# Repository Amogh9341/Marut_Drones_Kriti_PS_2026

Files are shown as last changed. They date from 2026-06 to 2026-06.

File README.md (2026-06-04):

# Drone-Based Seedball Dispersal Payload
**Aeromodelling Marut Drones | Kriti '26 | IIT Guwahati | Hostel ID: 2651**

---

## Problem Statement

Manual reforestation is precise but slow. Traditional aerial broadcasting is fast but wasteful — seeds cluster, land on unsuitable surfaces, and compete for resources. There is no reliable, autonomous mechanism that drops seedballs one at a time at controlled intervals from a drone, especially when seedball sizes are non-uniform.

---

## Idea

Design a standalone, drone-mounted payload system that:
- Releases seedballs **one at a time** at adjustable intervals (1–5 seconds)
- Handles **non-uniform spherical seedballs** (15–35 mm diameter)
- Operates **autonomously** — detects and resolves jams without human intervention
- Fits within **20 kg** total mass and **300 × 350 × 350 mm** volume

Design approach: *working backwards from failure* — identify what goes wrong in seed dispensing systems first, then build around those failure modes.

---

## Implementation

### Architecture: Three-Stage Modular Pipeline

**Stage 1 — Hopper Assembly**
- Gravity-fed tapered storage container
- Integrated rotational agitator (DC geared motor) prevents bridging and seed stagnation
- Capacity: up to 20 kg total (mechanism + seedballs)

**Stage 2 — Horizontal Screw Conveyor (Auger)**
- Meters seedballs from hopper to dispensing stage
- Acts as a buffer — decouples hopper pressure from dispensing rate
- Driven by a stepper motor; monitored via TMC2209 driver for stall detection
- On jam: auto-reverses motor up to 3 times, then halts safely

**Stage 3 — Disc Dispensing Mechanism**
- Continuously rotating disc with 3 conical radial grooves at varying angles
- Accommodates all seedball sizes (15–35 mm) without manual adjustment
- Releases exactly one seedball per cycle through a single drop point

### Control System
- **Microcontroller:** ESP32
- **Motor driver:** TMC2209 (built-in stall detection — no external sensors needed for jam detection)
- **Interface:** Bluetooth / Wi-Fi input for start/stop and drop interval setting
- **Fault logic:** Jam detected → reverse motor → retry up to 3 times → halt if unresolved

### Materials
- **Carbon fiber** — structural frame (lightweight, high tensile strength)
- **Acrylic sheet** — housing panels (easy to fabricate, optically clear for inspection)

### Key Design Tolerances
- Internal flow paths sized at **1.15× the largest seedball diameter** to allow for size variation without multi-ball release
- Seed drop interval: **1–5 seconds** (adjustable)

---

## Prototype

Built at **1:2 scale** (14 × 17 × 22 cm footprint) using carbon fiber and acrylic.  
Test seedballs: ~13 mm diameter (50% scale).  
Validated: gravity-fed dynamics, auger flow consistency, stall detection, and automated anti-jam routine.

---

## Limitations

- Risk of multi-seedball release cannot be fully eliminated
- Sensitive to mechanical tolerances in screw and disc assemblies
- Moisture and debris can affect flow behaviour
- Maintenance automation (dust/earth accumulation) is unsolved

---

## Future Scope

- GPS-based location-aware seedball deployment
- Active gating for improved single-ball precision
- Multi-drone swarm synchronization for large-scale restoration
- Automated rinsing/cleaning mechanism

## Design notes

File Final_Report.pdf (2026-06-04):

February 2026

Final Technical Report

Kriti ’26

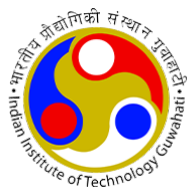
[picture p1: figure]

——————————————————–

AEROMODELLING MARUT DRONES

——————————————————–

Hostel ID:

2651

## Contents

Kriti ’26 | Hostel : 2651

## 1 Introduction

Drone based reforestation addresses one of the biggest challenges in environmental restoration: how to plant on a scale without sacrificing survival rates. Manual planting is precise but slow, while traditional aerial broadcasting where seeds are scattered in bulk is fast but wasteful. Many seeds end up clustered together or fall on unsuitable surfaces such as rocks, reducing their chances of survival. A drone system that releases seedballs one at a time, at controlled intervals, offers a more balanced approach combining efficiency with precise placement for large-scale planting efforts.

By dropping seedballs at regular intervals, each plant gets a equal share of sunlight, water, and nutrients from the soil, reducing unnecessary competition. Without this controlled spacing, seeds often fall in clusters, leading to overcrowded patches where only the strongest seedlings survive. At the same time, other areas are left empty, making them more prone to invasive species taking root.

### 1.1 Importance of timing and control

Consistent timing and accurate drop control are not just operational details they play an important role in ensuring meaningful and sustainable results. In drone based reforestation, the overall success of plantation efforts depends greatly on how precisely seed placement is managed during flight. When release intervals are uniform, plant spacing becomes more predictable, survival rates improve, and land coverage becomes more efficient.

1.1.1 Uniform Timing: It keeps the drone’s speed and seed release perfectly in sync, so the drops form a pattern, regardless of wind or terrain.

1.1.2 Seed Drop Control: Guarantees that only one seedball is released at a time, preventing mechanical jams and ensuring that the seedballs are used efficiently.

### 1.2 Problem Definition

The primary challenge is to address the limitations of traditional manual reforestation—such as high labor costs and limited access to rough or protected terrains—by utilizing drone technology. Current aerial seeding solutions are often hindered by mechanical jamming caused by non-uniform seedball sizes and a lack of precision control over dispensing rates. Consequently, there is a need for a reliable and intelligent payload system that can autonomously manage seedball dispersal in remote environments.

### 1.2.1 Project Scope and Requirements

We are tasked with designing and developing a standalone seedball dropping mechanism to be mounted on a drone. The project focuses exclusively on the payload system; the drone’s flight control and propulsion are out of scope.

### 1.2.2 Core Requirements:

1.2.2.1 Storage & Capacity: The system must be of up to 20 kg including both the mechanism aswell the seedballs within a maximum volume of 300 mm x 350 mm x 350 mm.

1.2.2.2 Material Handling: It must reliably process non-uniform, irregular spherical seedballs with diameters ranging from 15 mm to 35 mm.

1.2.2.3 Precision Dispensing: The mechanism must allow for adjustable drop intervals between 1 and 5 seconds.

1.2.2.4 Autonomous Intelligence: The system must include onboard electronics like ESP32 and sensors to detect and automatically rectify blockages or jams without human intervention.

### 1.3 Constraints

1.3.1 Mass Limits: The total allowable mass, including the dispensing mechanism and seedball payload, is capped at 20 kg.

### 1.3.2 Physical Constraints

Maximum payload volume: Width: 300 mm, Height: 350 mm, Length: 350 mm Seedball size range: Diameter: 15 mm to 35 mm
Shape: Non-uniform / irregular spherical
Weight optimization for aerial deployment

1.3.3 Controlled seedball drop interval: 1-5 seconds.

### 1.3.4 Vessel and Screw Placement

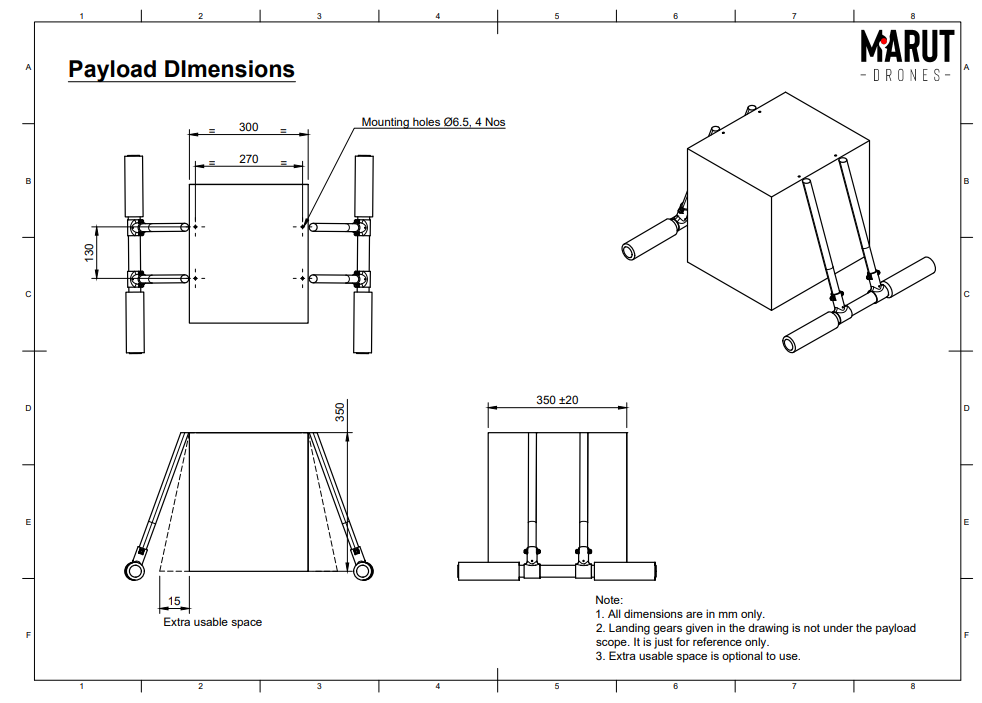
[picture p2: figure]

## 2 Conceptual Ideation

This section covers the evolution of design ideas explored for the seedball dispensing system, highlighting the reasoning behind different concepts and the criteria used to evaluate them.

### 2.1 Objective and Methodology

### 2.1.1 Thinking Structure : Working Backwards

To get a suitable design, we first examined what typically goes wrong in seed dispensing systems rather than assuming an optimal mechanism from the outset while also ensuring that the drop needs to be the same every time, regardless of how full the hopper is.

(a) How do we stop seeds from clumping? Seeds naturally want to stick together; we need to break that bond.
(b) How do we handle different sizes? A mechanism for a 15 mm seed might crush or jam a 35 mm seed.
(c) How do we ensure only one drop? We need a way to “queue” the seeds so they do not all rush out at once.

### 2.1.2 Concept Research Plan

The research was centered on existing industrial systems designed to solve similar problems.

(a) Seed Storage Vessels: The research examined factors that contribute to arch formation such as particle size variation, wall friction, and hopper geometry and explored design strategies to minimize these issues.
(b) Vending Machines: Examined spiral dispensing mechanisms commonly used in vending machines to understand how they isolate and release single items per rotation. The study focused on how rotational pitch, pocket spacing, and controlled motor actuation prevent multiple releases while maintaining consistent and jam-free operation.

### 2.1.3 Purpose of Mechanisms

We simplified the design by dividing the mechanism into basic components, each responsible for one clearly defined function.

(a) Auger: A screw that moves a steady volume of seeds forward.
(b) Disc: A rotating plate that catches one seed and drops it at a set interval.
(c) Agitator: A stirrer that keeps the seeds moving so they don’t get stuck in the hopper.

### 2.2 Design Constraints and Tolerances

The final mechanism was developed within clearly defined mechanical, operational, and environmental constraints to ensure reliable performance under real-world drone deployment conditions.

### 2.2.1 Failsafe Mechanisms

(a) Agitator: Keeps the ”pile” loose so the main screw always has seeds to grab, and prevents arching of seeds.
(b) Directional Reversal: When a stall is identified, the controller initiates a brief reverse rotation of screw for 2% of seed dropping time period to clear the jam and restore normal seed flow.

### 2.2.2 Seed Tolerance Limits

We set a target range for seeds between 15mm and 35mm.

(a) To minimize the risk of jamming, all internal flow paths are designed with some extra space usually around 1.15 times the diameter of the largest seedball. This allows for natural size variation, surface irregularities, and small shifts during motion. As a result, the seedballs move more smoothly through the system, lowering the risk of clogging or mechanical interference..
(b) If the clearance is too small, friction and obstruction can increase to the point where the motor stalls or the mechanism jams. Conversely, if the gap is too large, more than one seedball can slip through at the same time, which affects the accuracy of single drops and disrupts the spacing consistency.

## 3 Mechanism

### 3.1 Engineering Logic & Design Philosophy

The seedball dispersal payload proposed aims to solve the major issues in aerial seeding like flow inconsistency, jamming, and seedball size variation while at the same time, focusing on reliable and autonomous operation within drone’s weight, volume, and power limitations for remote, sensitive environments. It uses gravity assisted feeding combined with controlled mechanical transport to separate bulk storage from dispensing, thus, delivering consistent output across different fill levels and reducing blockages/ uncontrolled release to the minimum.
Using simple, modular, and commercial parts helps to increase manufacturability, maintenance, and scalability, thus, they strike a balance between engineering rigor and practical usability to ensure reliable performance.

### 3.2 Major Hardware Components

The payload consists of three primary mechanical subsystems. The hopper assembly serves as the seedball storage unit and incorporates a tapered geometry with integrated rotational agitation to ensure consistent feeding of non-uniform seedballs. The horizontal screw conveyor (auger) provides controlled, metered transport of seedballs from the hopper to the dispensing stage while acting as a buffer against flow surges. Final release is achieved through disc dispensing mechanism, where a continuously rotating dispensing disk, featuring conical radial grooves with varying incident angles, accommodates different seedball sizes for controlled and sequential discharge through a single release point.

### 3.3 Technical Specifications

The technical specifications of the proposed seedball dispersal payload are defined to ensure reliable operation within the mechanical, electrical, and spatial constraints of a drone-mounted system. Key specifications are summarized below.

(a) Overall mass:
- Maximum total payload mass (mechanism + seedballs): 20 kg.
- Designed with conservative margins to account for dynamic loads and vibration during flight.
(b) Dimensional constraints:
- Maximum length: 350 mm
- Maximum width: 300 mm
- Maximum height: 350 mm
(c) Seedball Parameters:
- Average seedball diameter: 32 mm (varying form 15mm to 35mm)
- Average seedball mass: 27 g
(d) Hopper Assembly:
- Gravity-fed hopper with tapered geometry
- Internal rotational agitator to prevent bridging and stagnation driven using DC geared motor
(e) Screw Conveyor:
- Horizontally mounted threaded screw for metered transport
- Driven by a stepper motor selected based on torque requirements
(f) Dispensing Mechanism:
- Disc with three conical grooves of different angular widths to accommodate seedballs of all varied sizes.
- The open grove collects the balls dropped by the screw and carries it till the dropping hole through its rotation
(g) Control System:
- Microcontroller-based architecture with ESP32

- Controls motor actuation, sensor inputs, and fault response logic
(h) Sensors and Monitoring:
- TMC2209 Motor stall sensing for screw and disc jamming detection
(i) Power and Electrical Interface:
- Powered directly from the drone’s onboard battery
- Includes voltage regulation, protection circuitry, and internal power distribution
(j) Structural Materials:
- Carbon Fiber : Lightweight with High Tensile strength
- Acrylic Sheet : Easy for fabrication and gives optical clarity

### 3.3.1 Intended Payload

The proposed seedball dispersal payload is designed to operate within the constraints of a drone-mounted system while ensuring reliable mechanical and control performance. The total payload mass, including the mechanism and seedballs, is limited to 20 kg, and the system is packaged within approximate dimensions of 350 mm × 300 mm × 350 mm. It is designed to handle seedballs with diameters ranging from 15mm to 35mm, while accommodating reasonable geometric variation. The hopper features a gravity-fed tapered geometry with integrated rotational agitation to prevent stagnation. Seedball transport is achieved using a horizontal screw conveyor, and controlled dispensing is provided by a disc mechanism with varied groves for multiple seedball dimensions. A microcontroller-based system manages actuation, sensing, and fault detection, with power drawn directly from the drone’s onboard supply.

### 3.3.2 Detailed CAD Views of Components

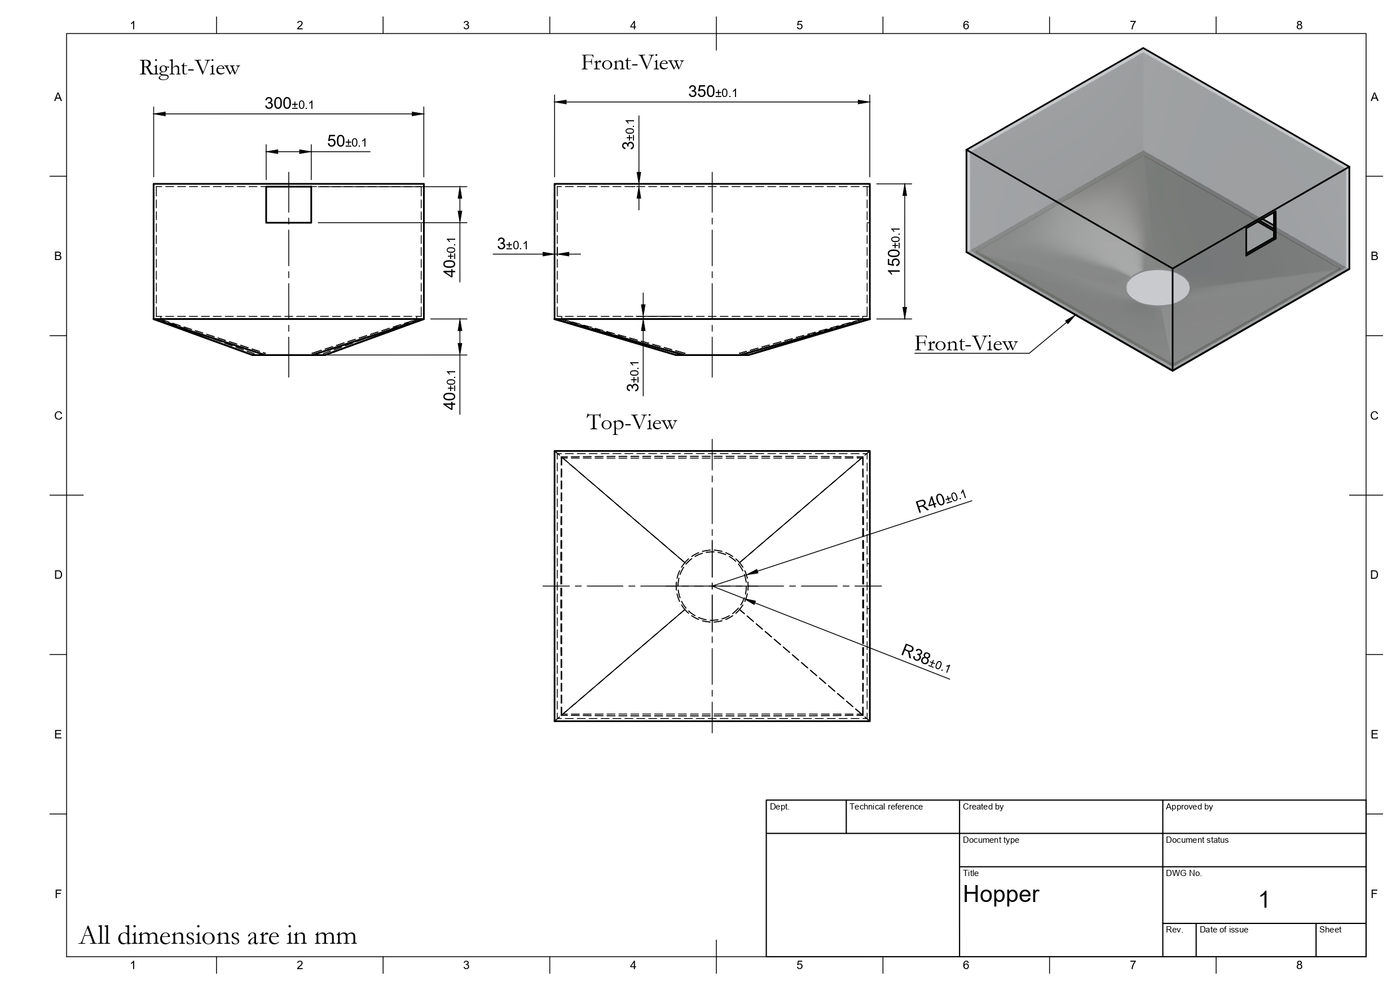
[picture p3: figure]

Figure 1: Hopper

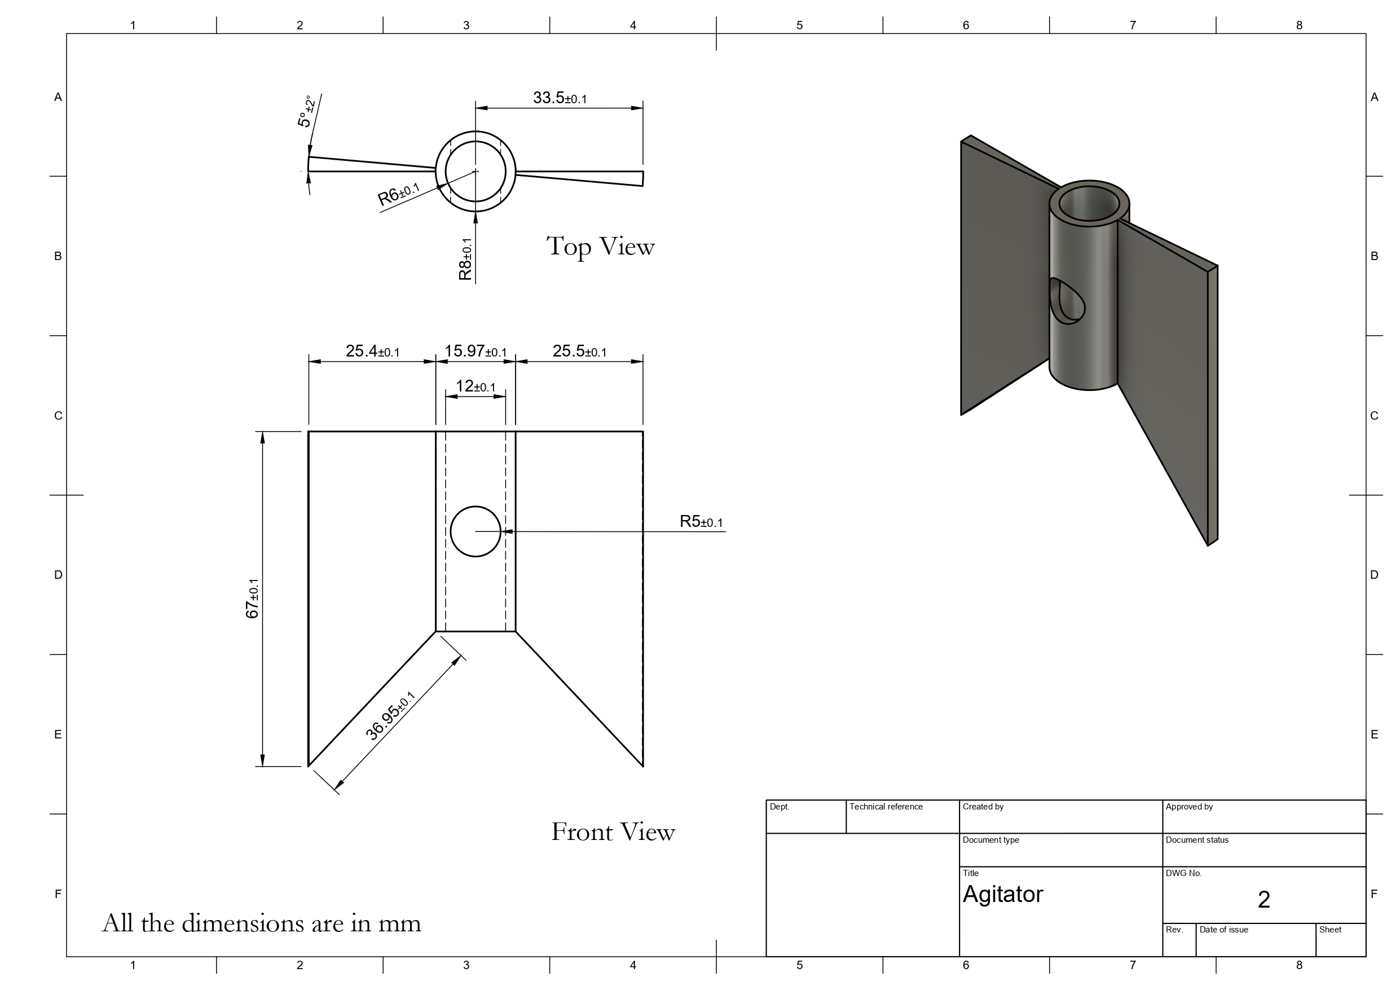
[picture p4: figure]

Figure 2: Agitator

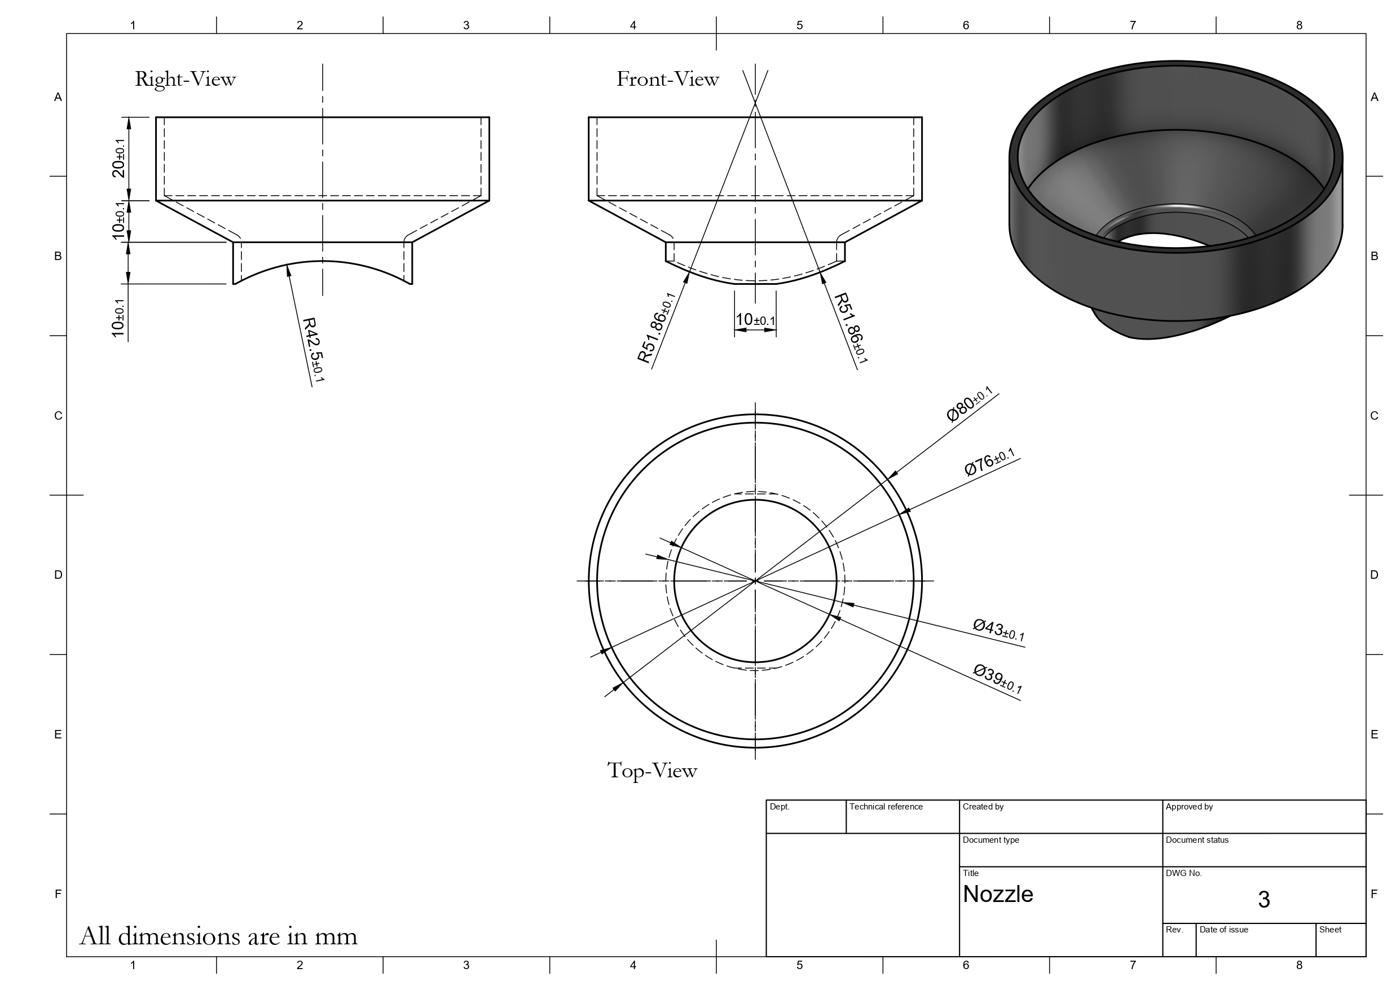
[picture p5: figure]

Figure 3: Hopper Nozzle

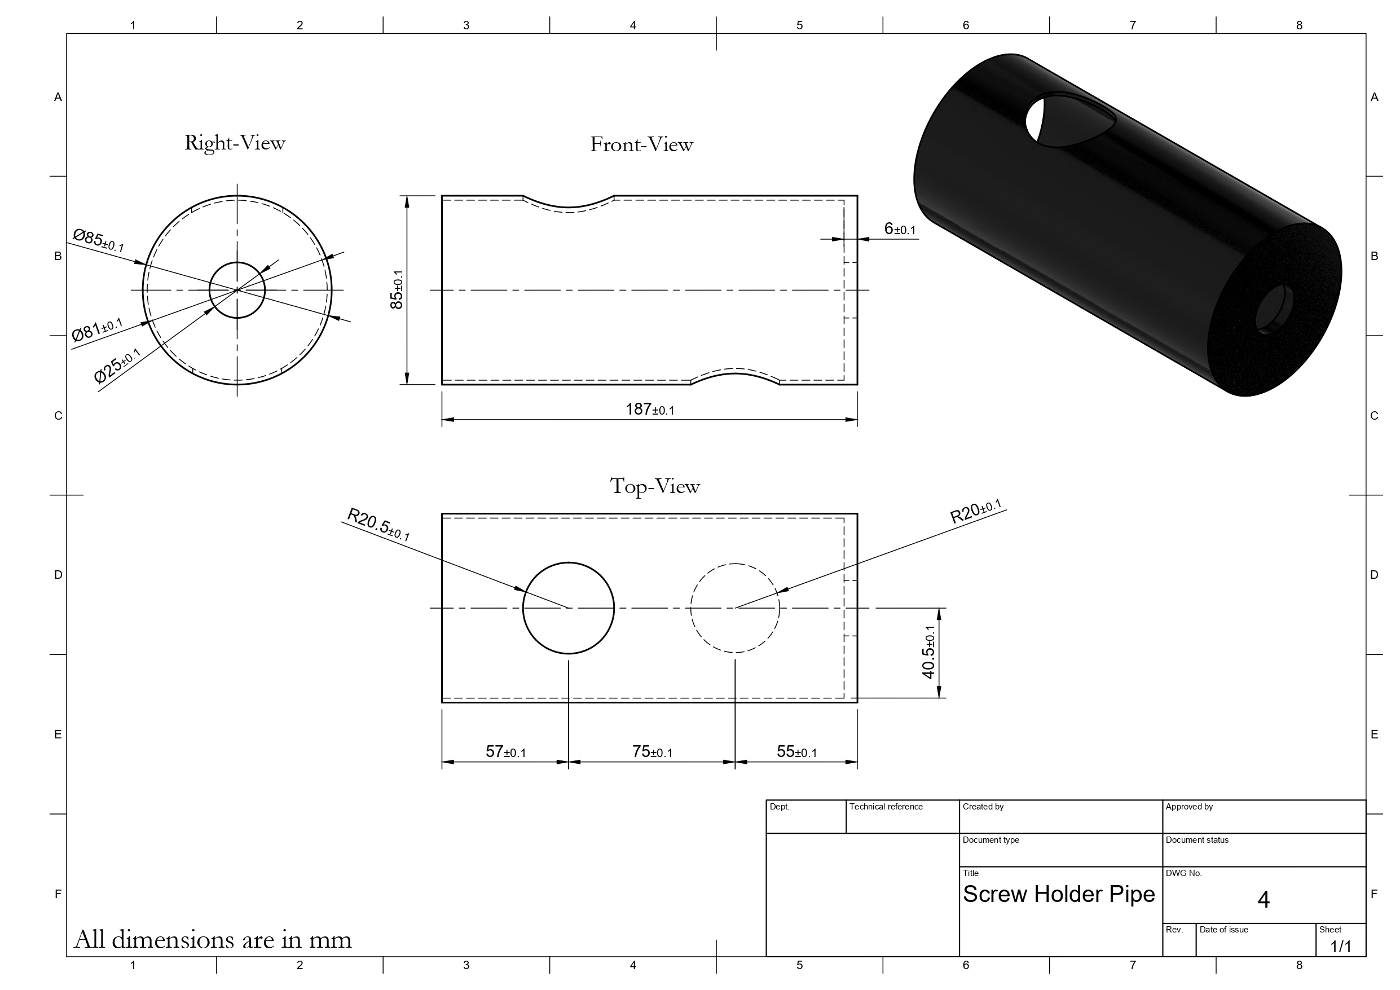
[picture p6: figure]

Figure 4: Screw Holder

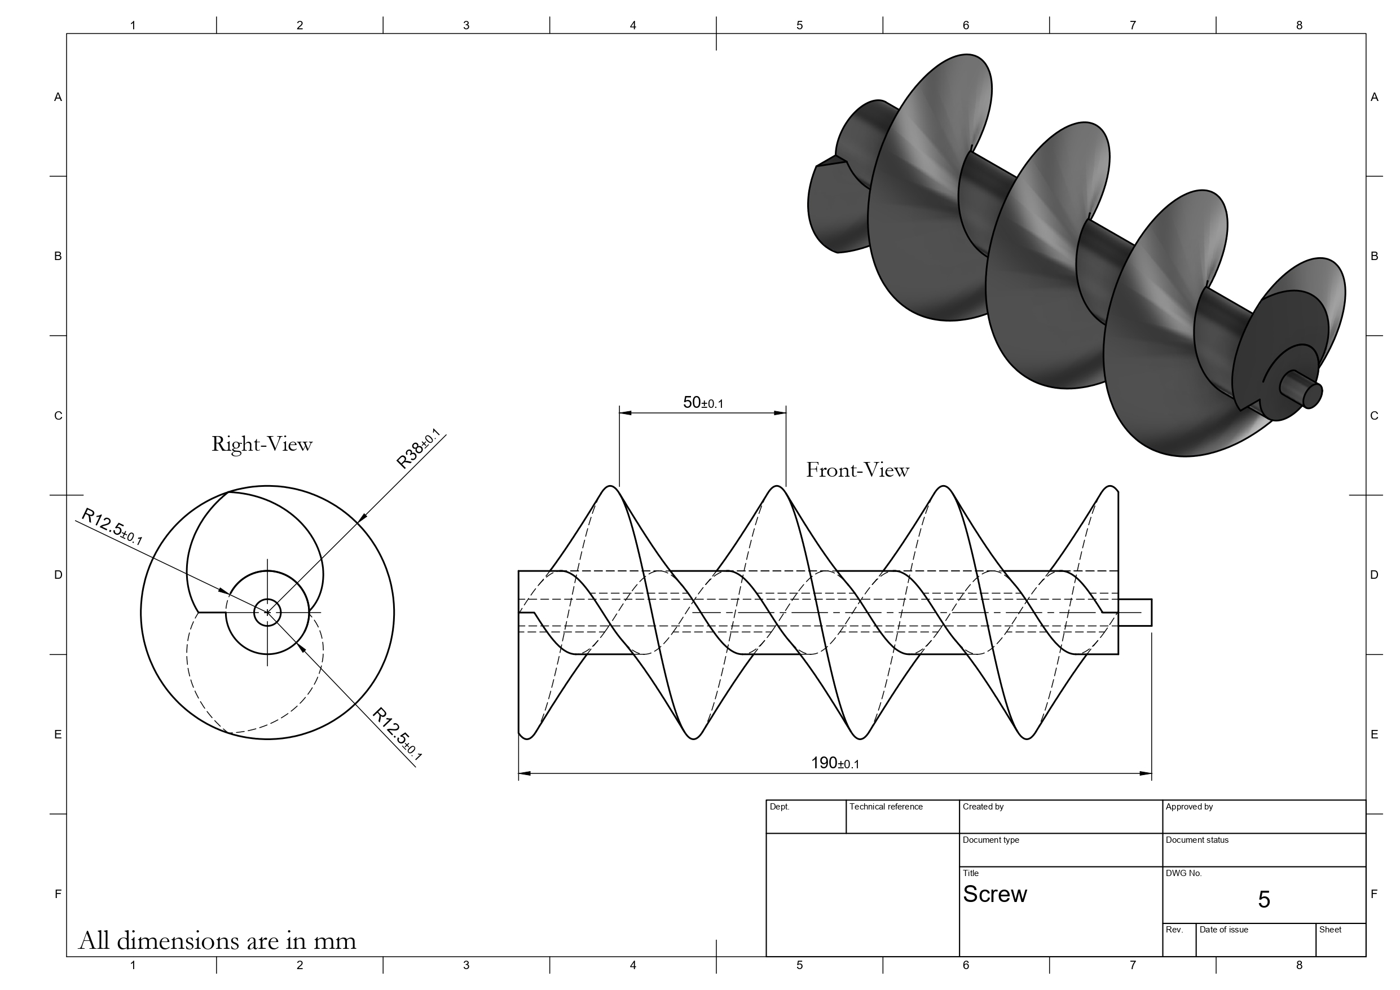
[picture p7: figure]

Figure 5: Screw

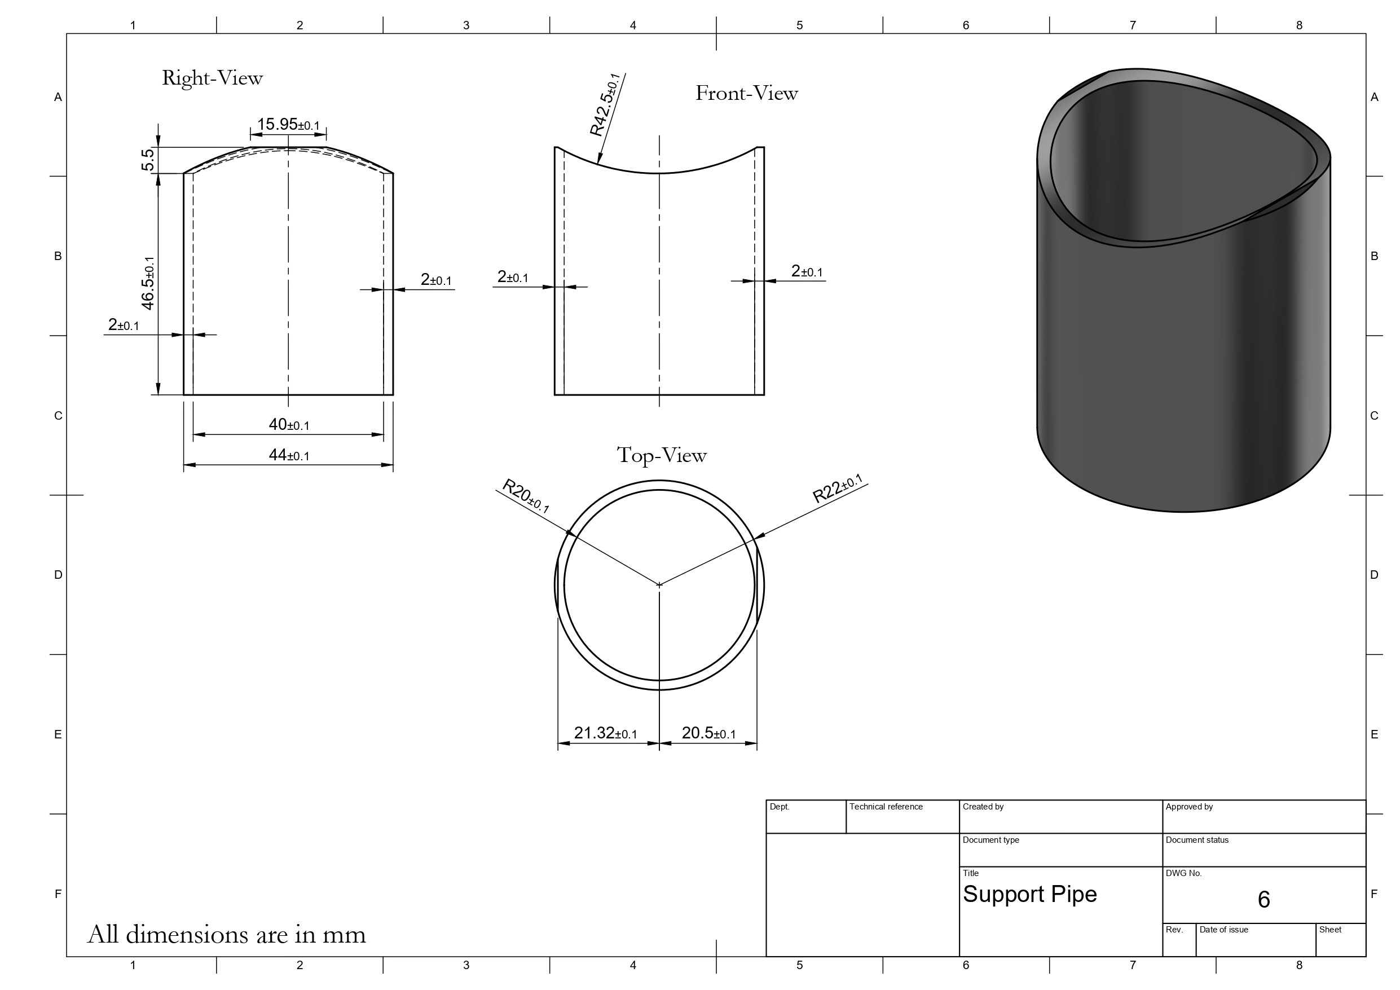
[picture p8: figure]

Figure 6: Support Pipe

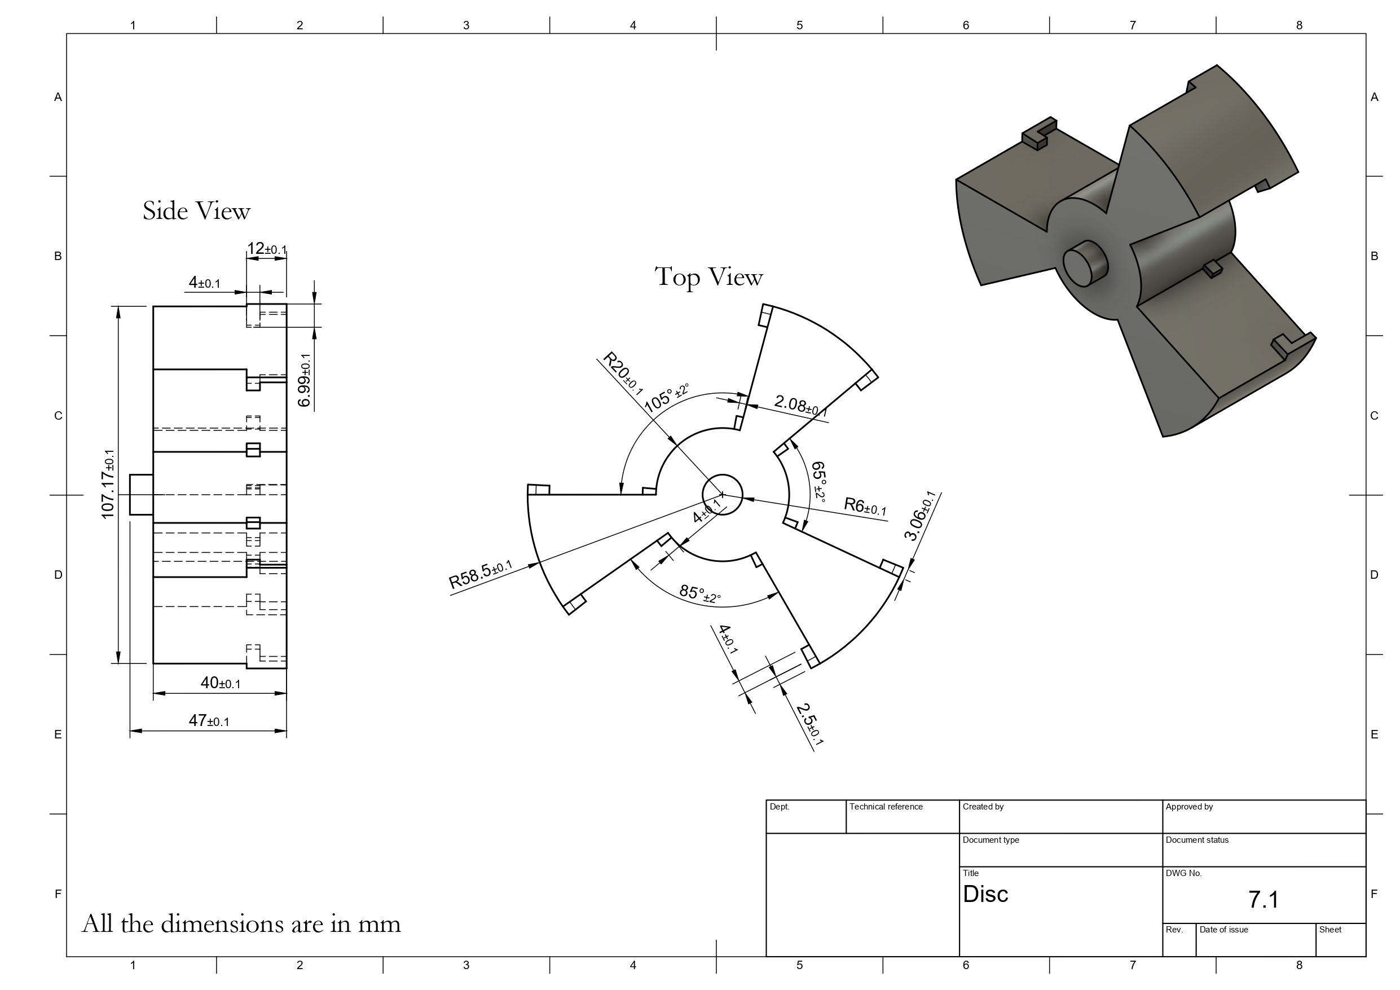
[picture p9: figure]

Figure 7: Disc(A)

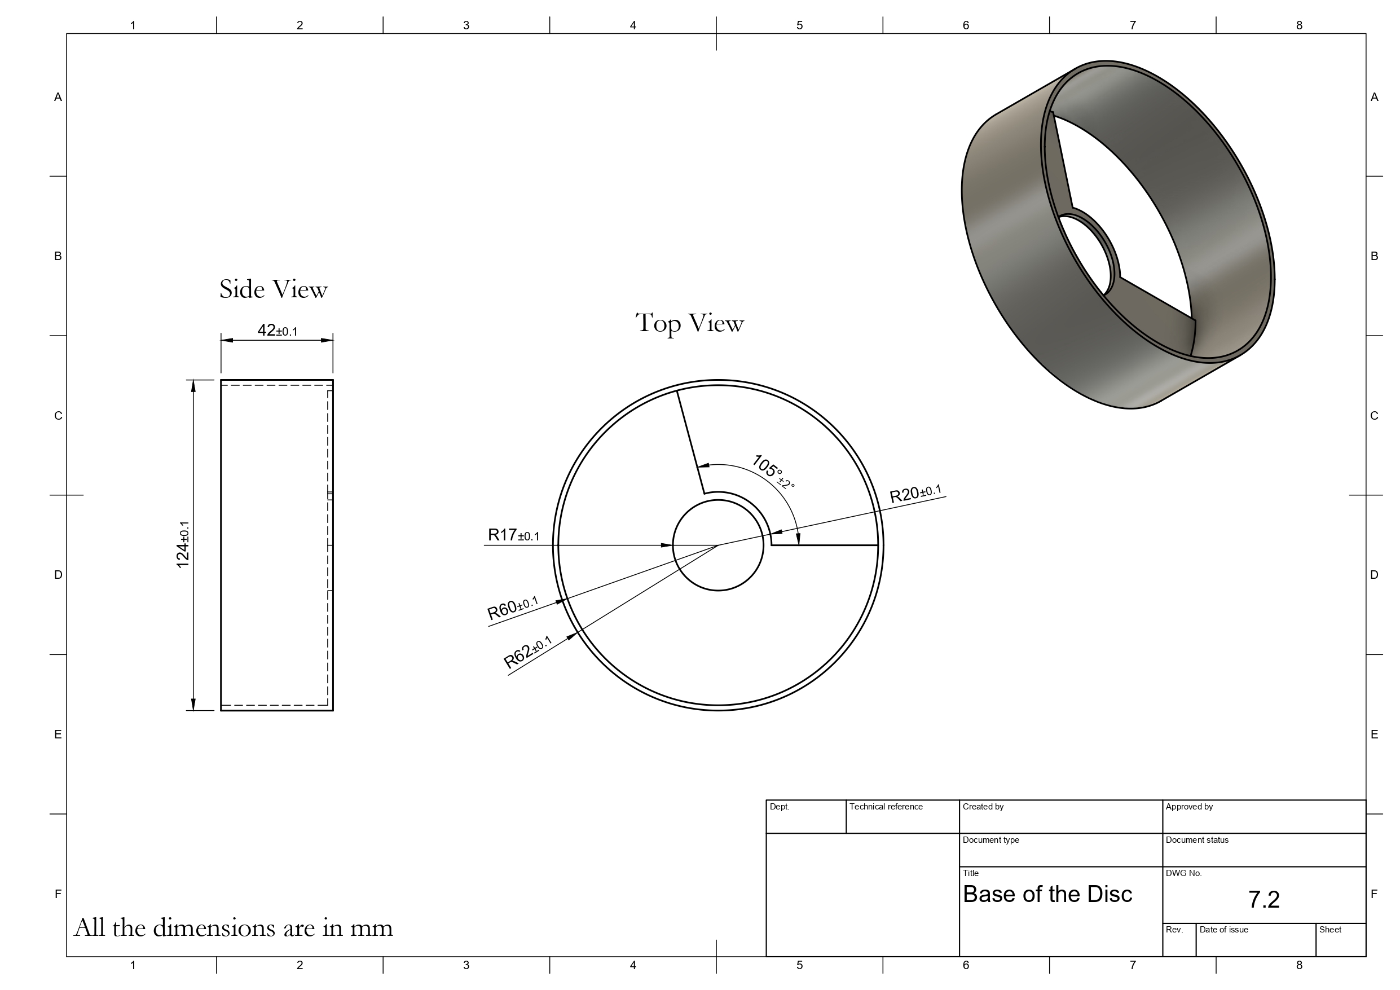
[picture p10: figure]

Figure 8: Disc(B)

### 3.3.3 Cost Analysis

A detailed breakdown of the material and component expenses for the fabricated prototype is provided below.

Table 1: Cost Analysis

Item | Cost (Rs)
Carbon fiber filament | 575
Acrylic Sheet | 360
Microcontrollers
Actuators (3)
Motor Drivers
Miscellaneous costs

Total

### 3.4 Free Body Diagrams

The free body diagrams of the seed-ball in hopper[Fig 9a] and horizontal auger[Fig 9b] are as follows :

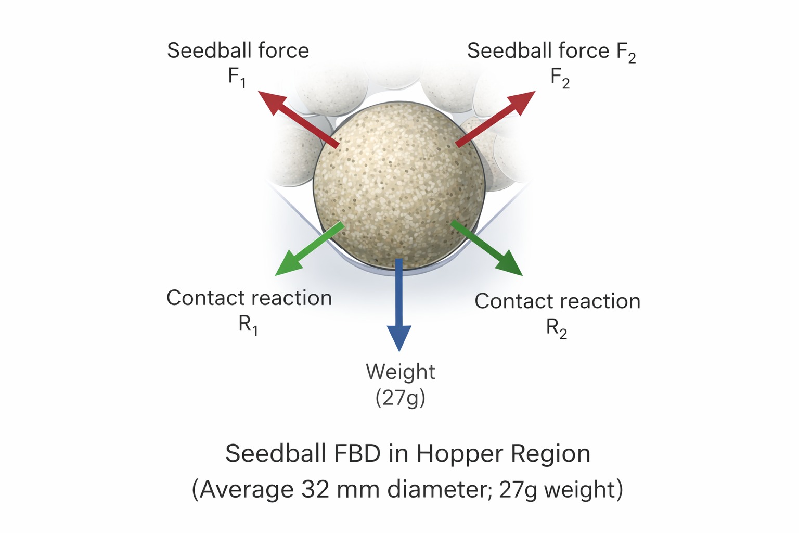
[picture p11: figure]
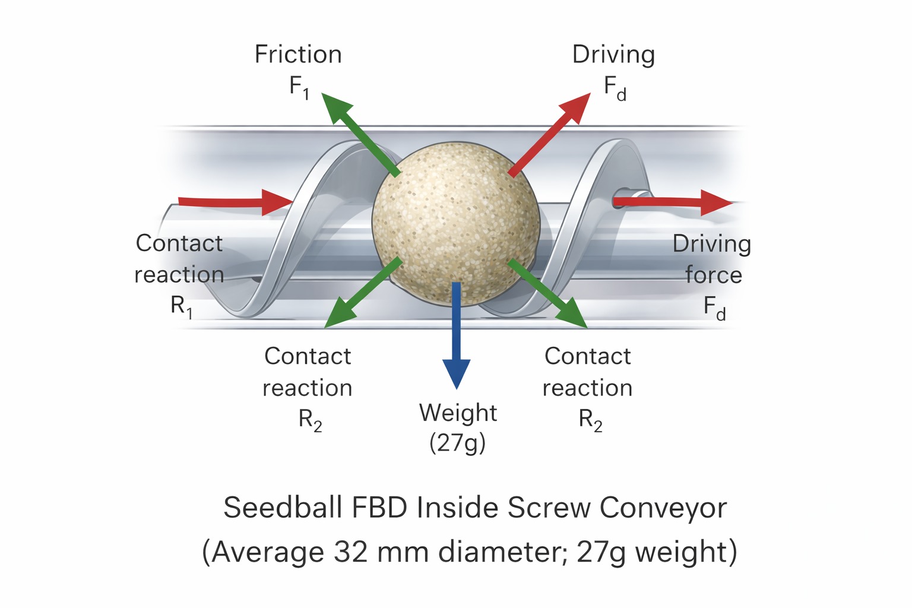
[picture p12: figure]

(a) In Hopper | (b) In Auger

Figure 9: Free Body Diagrams

### 3.5 Control Logic

During operation, seedballs flow from the hopper aided by continuous mechanical agitation to prevent stagnation. They are then metered by a horizontal screw conveyor actively monitored by a TMC2209 stepper driver. If jamming occurs, integrated stall detection triggers an automated anti-jam routine, reversing the motor up to three times to clear the blockage before safely halting the system. Upon exiting the screw, seedballs are sequentially caught by a continuously rotating dispensing disk featuring conical radial grooves with varying incident angles. This geometry dynamically accommodates dimensional variations, ensuring a controlled and repeatable release through a single drop point

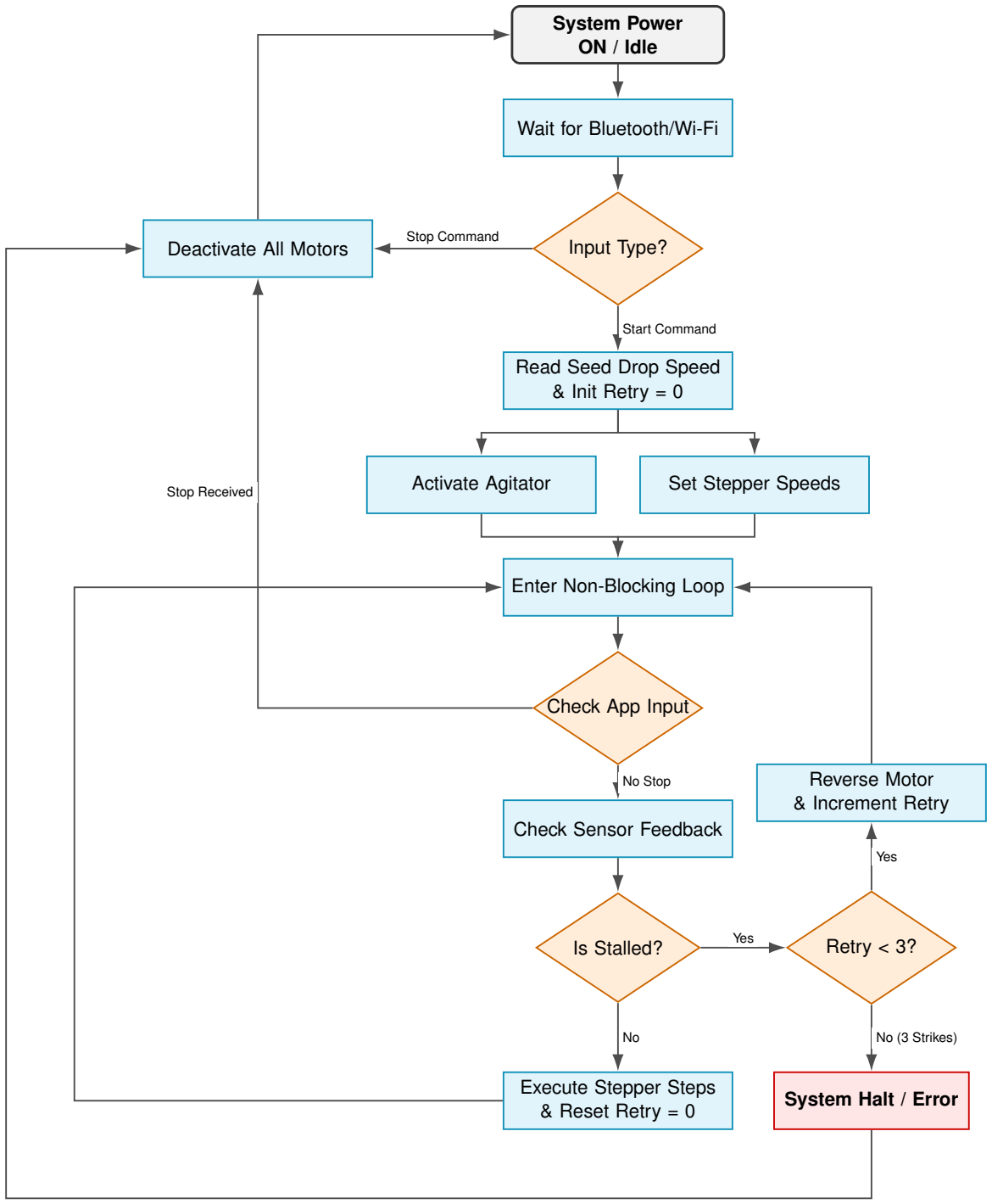
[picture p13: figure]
System Power ON / Idle; Wait for Bluetooth/Wi-Fi; Input Type?; Read Seed Drop Speed & Init Retry = 0; Activate Agitator; Set Stepper Speeds; Enter Non-Blocking Loop; Check App Input; Check Sensor Feedback; Is Stalled?; Execute Stepper Steps & Reset Retry = 0; Deactivate All Motors; Retry < 3?; Reverse Motor & Increment Retry; System Halt / Error; Stop Command; Start Command; No Stop; Yes; No (3 Strikes); Stop Received

Figure 10: Control Flow Logic of the Seedball Mechanism.

### 3.6 Reliability: Blockage Points & Resolution Logic

### 3.6.1 Jamming and Failures

The potential blockage (jamming) points are as follows:

(a) Hopper throat: Arching/bridging, ratholing, interlocking, overloading, moisture clumping, wall adhesion, dead zones.
(b) Agitator: Peripheral dead zones, jamming.
(c) Hopper Outlet: Wedging at lip/screw, misalignment, screw backpressure.
(d) Screw Conveyor: Jams in flights, crushing/lodging, no advance, fill/speed issues, foreign particles, discharge buildup.
(e) Vertical Pipe: Direction changes, bouncing, undersized diameter, stacking, electrostatic adhesion.
(f) Disc Assembly: Seedball wedging in angular grooves, screw-to-disk timing mismatches, debris accumulation, and housing friction.
(g) Drone/Operational: Acceleration/deceleration, tilted flights, vibrations, motor starts/stops, resonance, expansion.
(h) General: Defective seedballs, dust, compaction, partial jams.

### 3.6.2 Detection

The system uses the TMC2209 driver’s built-in stall detection feature. It monitors the load variations for motor and can sense when resistance suddenly increases an indication that a jam may be forming allowing the system to respond quickly and prevent further blockage.

### 3.6.3 Solutions

To mitigate blockages, the system employs a combined hardware-software strategy. Mechanically, continuous hopper agitation prevents initial material bridging, while the dispensing disk’s varied radial grooves safely accommodate different seedball sizes without lodging. If a jam occurs in the screw conveyor, the TMC2209 driver detects the resistance spike via its integrated stall sensing. The control logic immediately triggers an automated anti-jam routine, reversing the motor to clear the obstruction. The system will attempt this up to three times; if successful, normal operation resumes and the retry counter resets. If the jam persists after three consecutive attempts, the system safely halts to prevent hardware damage.

### 3.7 Future Scope

Future developments will focus on enhancing dispensing precision by further minimizing the likelihood of multiseedball release through improved metering strategies and more precise control mechanisms. Additionally, the integration of GPS-based dispersal logic is envisioned to enable location-specific, mission-aware deployment of seedballs. Expanding beyond single-unit operations, future control software could enable multi-drone swarm synchronization for rapid, large-scale ecological restoration.

An issue which has not yet been solved is the automation of maintenance. The accumulation of earth is inevitable and handling it will require some kind of rinsing mechanism which is difficult.

### 3.8 Mechanism Summary

This section summarizes the overall performance, strengths, and limitations of the mechanism, providing a concise evaluation of its feasibility and practical implementation.

### 3.8.1 Overall feasibility statement

The proposed seedball dispersal mechanism is feasible within the mass, dimensional, and power constraints of a drone mounted payload. Its hybrid use of gravity assisted flow and mechanically metered transport enables reliable handling of non-uniform seedballs. With appropriate testing and calibration, the system is well-suited for autonomous aerial deployment.

### 3.8.2 Key Strengths

The major advantages of the mechanism are its ability to tolerate variations in seedball size, its multi stage jam prevention by means of agitation along with stall detection for motor reversal, and a modular design which makes it easier to maintain and upgrade in the future. In addition, sensor based monitoring helps to enhance the overall reliability of the machine during autonomous operation.

### 3.8.3 Risks and Limitations

The main limitations are that it is impossible to completely get rid of the risk of multi seedball release and the system is sensitive to mechanical tolerances in the screw and disc assemblies. Environmental factors like moisture and debris can also impact flow behaviour, which therefore requires controlled testing and refinement of the system.

## 4 Prototype Validation

### 4.1 Prototype Specifications and Scaling

To validate the mechanical logic and flow consistency of the proposed seedball dispersal payload, a physical prototype was fabricated at a 1:2 scale relative to the full-size design.

1. Dimensional Scaling: The original payload was designed to operate within maximum spatial constraints of 350 mm × 300 mm × 350 mm to fit standard drone-mounted parameters. The validation prototype successfully condensed this architecture into a compact 14 cm × 17 cm × 22 cm footprint, effectively halving the volumetric requirements while maintaining the spatial relationships between the hopper, horizontal auger, and dual-disc dispensing stages.
2. Seedball Parameters: To accurately test the gravity-fed dynamics and prevent false-positive jam testing, the prototype utilizes representative seedballs scaled down by approximately 50%. While the full-scale payload is designed to handle seedballs averaging 32 mm in diameter (varying from 15 mm to 35 mm), the validation testing relies on approximately 13 mm diameter test spheres. This ensures the geometric interaction between the seedballs, the rotational agitator, and the screw conveyor flights remains physically accurate to the original design philosophy.
3. Material and Component Selection: Transitioning from the theoretical design to a physical build required adapting the structural materials for rapid manufacturability and testing. The prototype’s primary structural framework and housing utilize a combination of carbon fiber and acrylic sheets, balancing rigidity with weight reduction. The system integrates the core control electronics, including the microcontroller and motor actuation hardware, directly into this scaled-down envelope. This allows for real-world testing of the TMC2209 driver’s stall detection capabilities and the system’s automated fault response logic within a representative physical space

### 4.2 Performance Analytics and Operational Metrics

## 5 Conclusion

The Horizontal Auger with Disc mechanism continues to be a real and mechanically strong solution for the controlled release of seedball drones in the air. This model solves the main issue of aerial reforestation, which is the regulated and even release of non uniform seedballs under the limiting conditions of weight, power, and reliability that come from deployment by a drone while at the same time minimizing the risk of jamming.

1. Decoupled Material Flow
The use of a horizontal screw conveyor as an intermediate buffer decouples the dispensing mechanism from the variable head pressure of the hopper. This isolation ensures predictable and metered material flow, reducing the likelihood of uncontrolled discharge and pressure-induced jamming.
2. Adaptive Precision
The Disc mechanism, incorporating conical openings of different angles made to accomodate different seedball dimensions, enables adaptive handling of seedballs with diameters ranging from 15 mm to 35 mm. This significantly reduces jamming risks commonly encountered in rigid, single-aperture systems and improves operational robustness.
3. Simplified Diagnostic Feedback
Jamming detection is achieved through monitoring motor stalling within the screw conveyor and disc assemblies. TMC2209 driver has stall detection to reliably detect stalling . Upon detection, the control logic can autonomously initiate temporary motor reversal without requiring external sensors.
4. Mass and Energy Efficiency
Combined with a lightweight carbon-fiber structural frame and direct power supply from the drone’s onboard battery, the module remains within the 20 kg payload constraint.
5. Future Scope
While the current configuration provides a robust foundation for reliable seedball dispersal, future iterations will focus on enhancing singulation precision through active gating mechanisms, fail safe operations integrating and mission-aware GPS-based deployment logic.

## 6 References

[1] K. To, P.-Y. Lai, and H. K. Pak, Jamming of Granular Flow in a Two-Dimensional Hopper, Phys. Rev. Lett. 86, 71–74 (2001).

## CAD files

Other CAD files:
CAD/Agitator.f3d
CAD/Assembly.f3z
CAD/Disc.f3d
CAD/Screw.f3z
CAD/Screw_Holder_Pipe.f3z
CAD/Support_Pipe.f3d
CAD/Vessel.f3d
CAD/Vessel_Nozzle.f3z

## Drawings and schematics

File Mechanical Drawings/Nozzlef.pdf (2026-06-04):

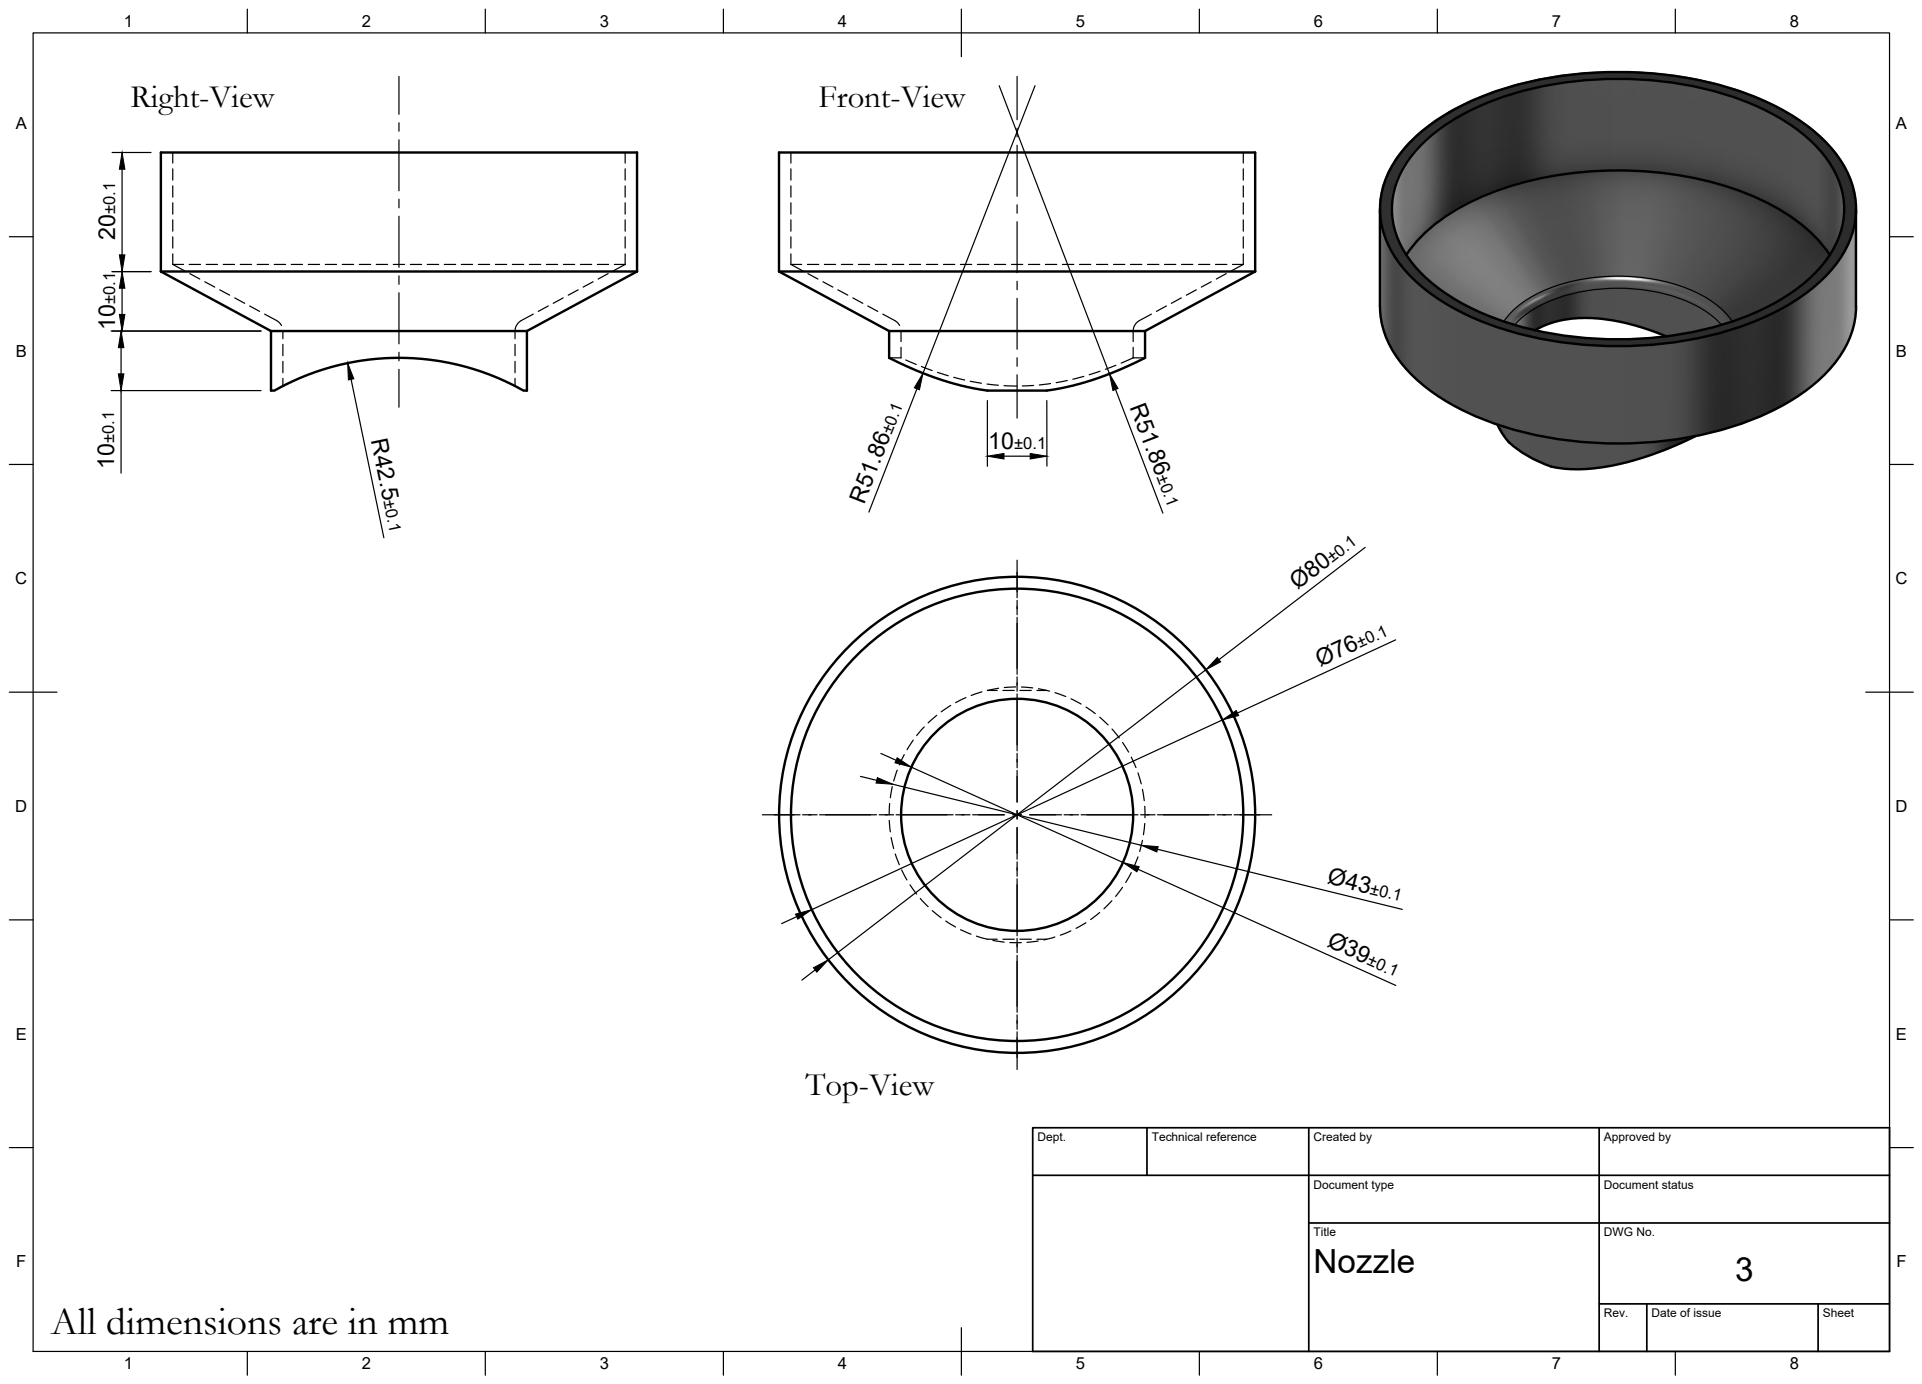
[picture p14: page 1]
Title; DWG No.; Rev.; Date of issue; Sheet; Nozzle

Dept. | Technical reference | Created by | Approved by

Document type | Document status

All dimensions are in mm

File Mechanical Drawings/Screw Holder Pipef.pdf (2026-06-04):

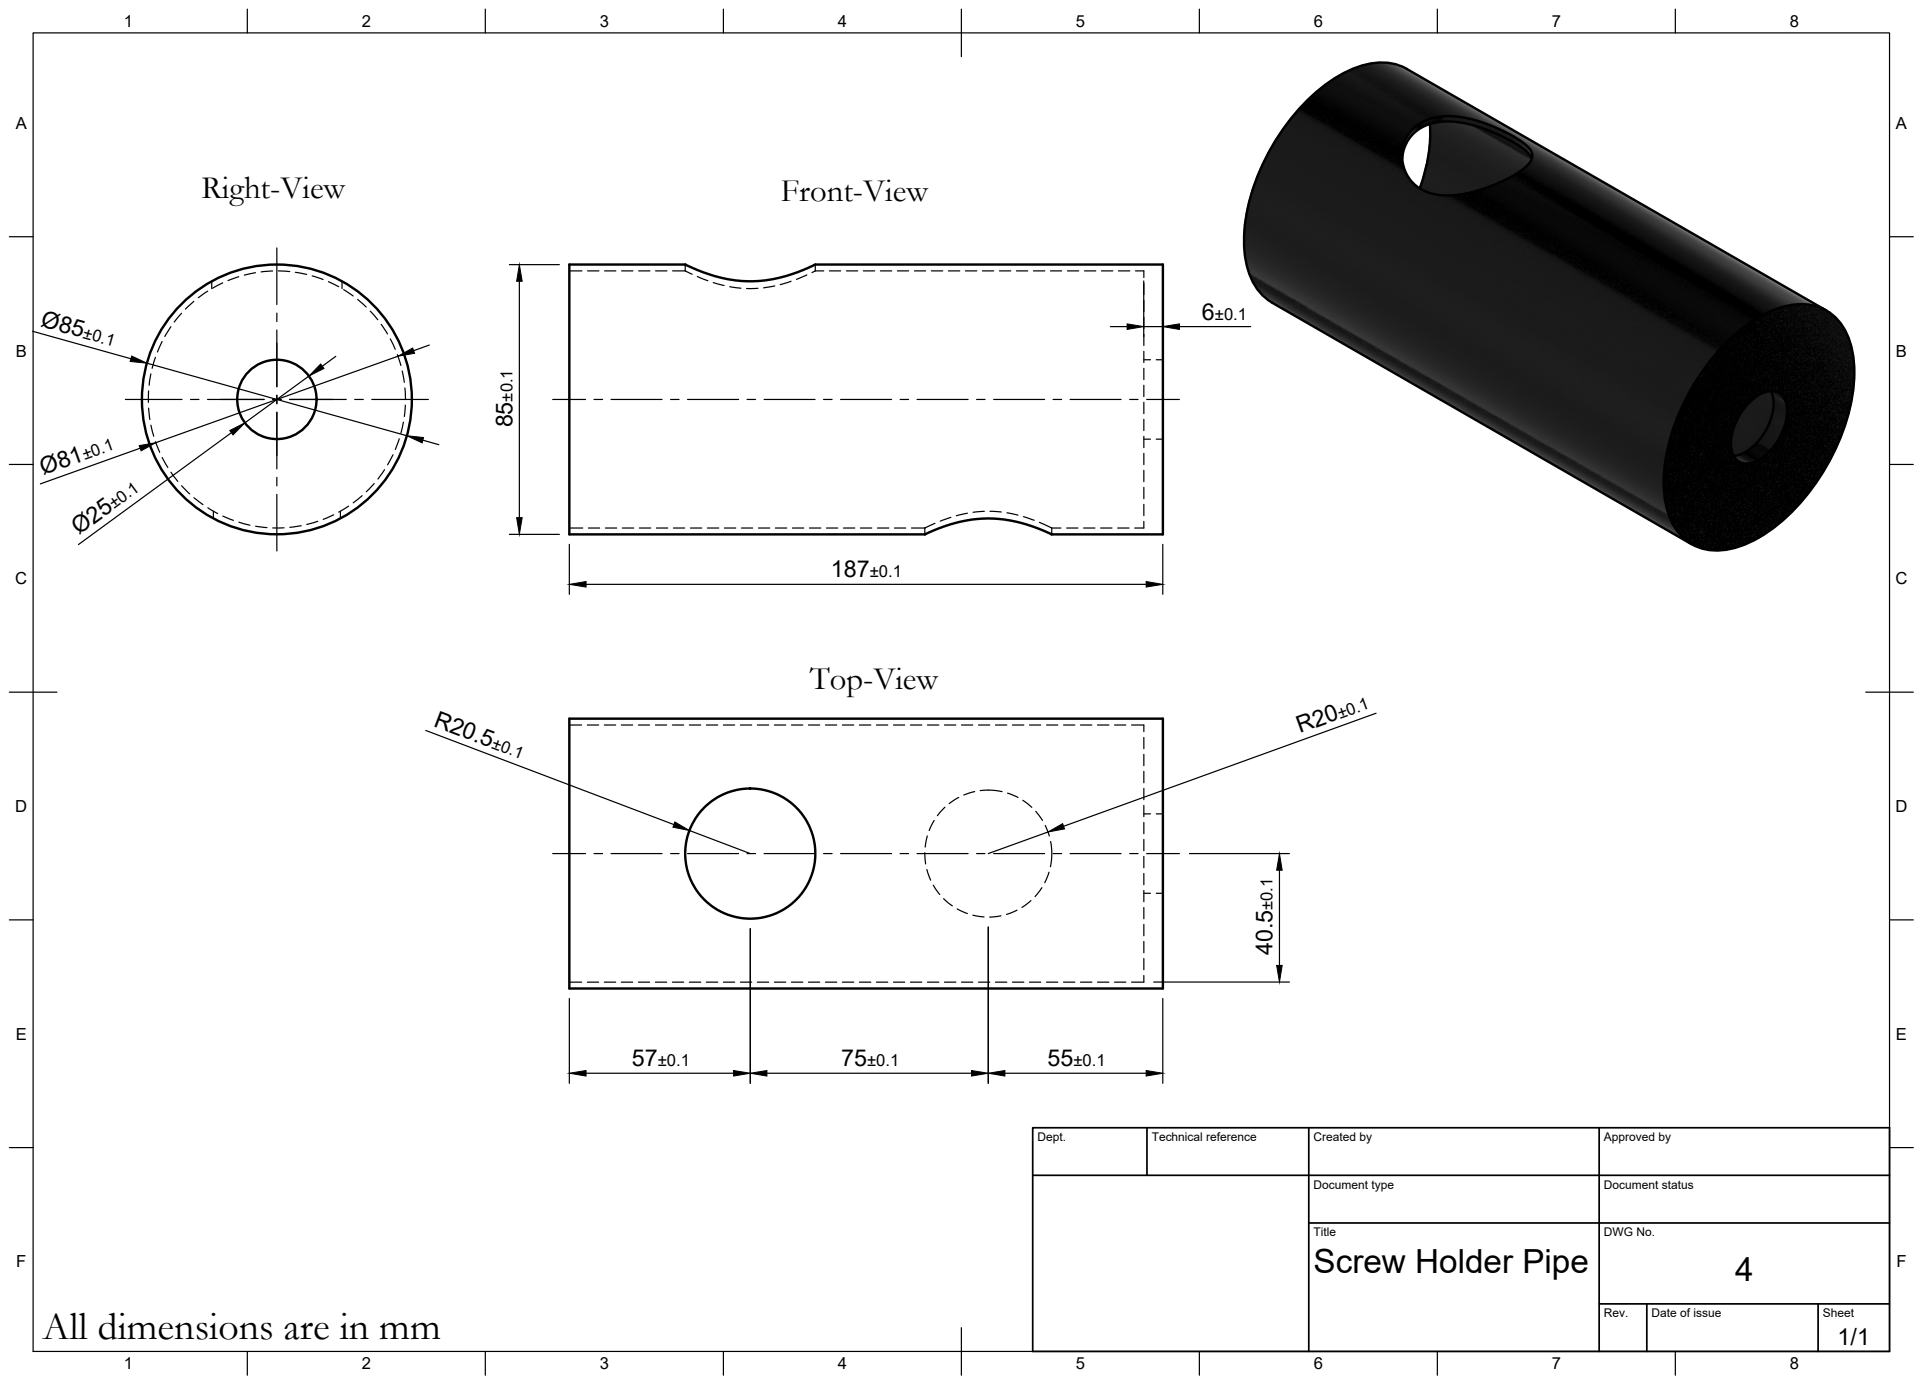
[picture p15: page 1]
Title; DWG No.; Rev.; Date of issue; Sheet; Screw Holder Pipe; Top-View 85±0.1

Dept. | Technical reference | Created by | Approved by

Document type | Document status

All dimensions are in mm

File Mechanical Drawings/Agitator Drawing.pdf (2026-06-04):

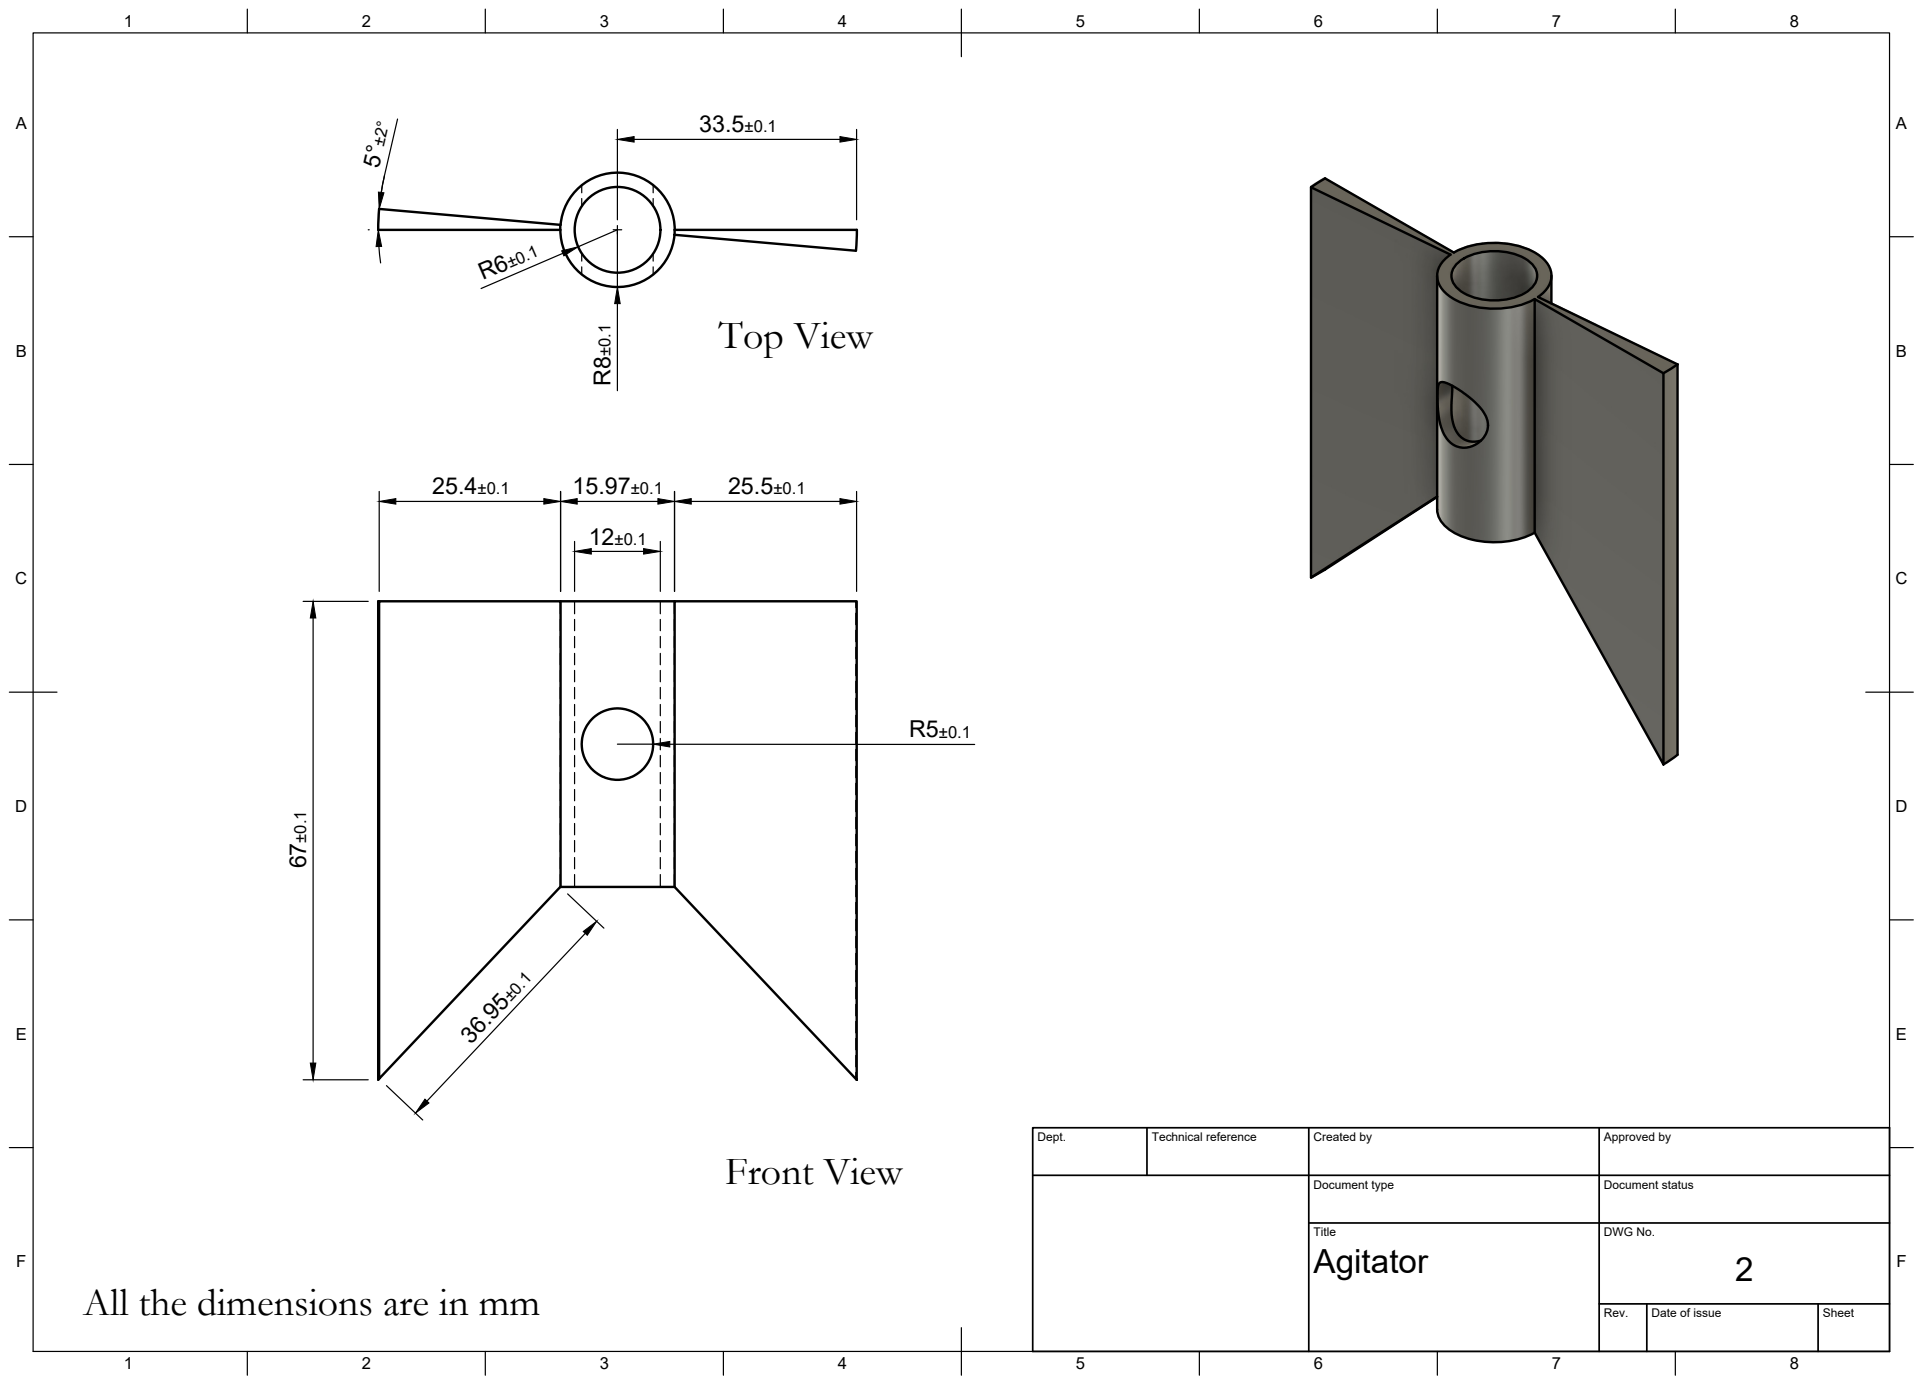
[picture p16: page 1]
Title; DWG No.; Rev.; Date of issue; Sheet; Top View; Front View

Dept. | Technical reference | Created by | Approved by

Document type | Document status

All the dimensions are in mm

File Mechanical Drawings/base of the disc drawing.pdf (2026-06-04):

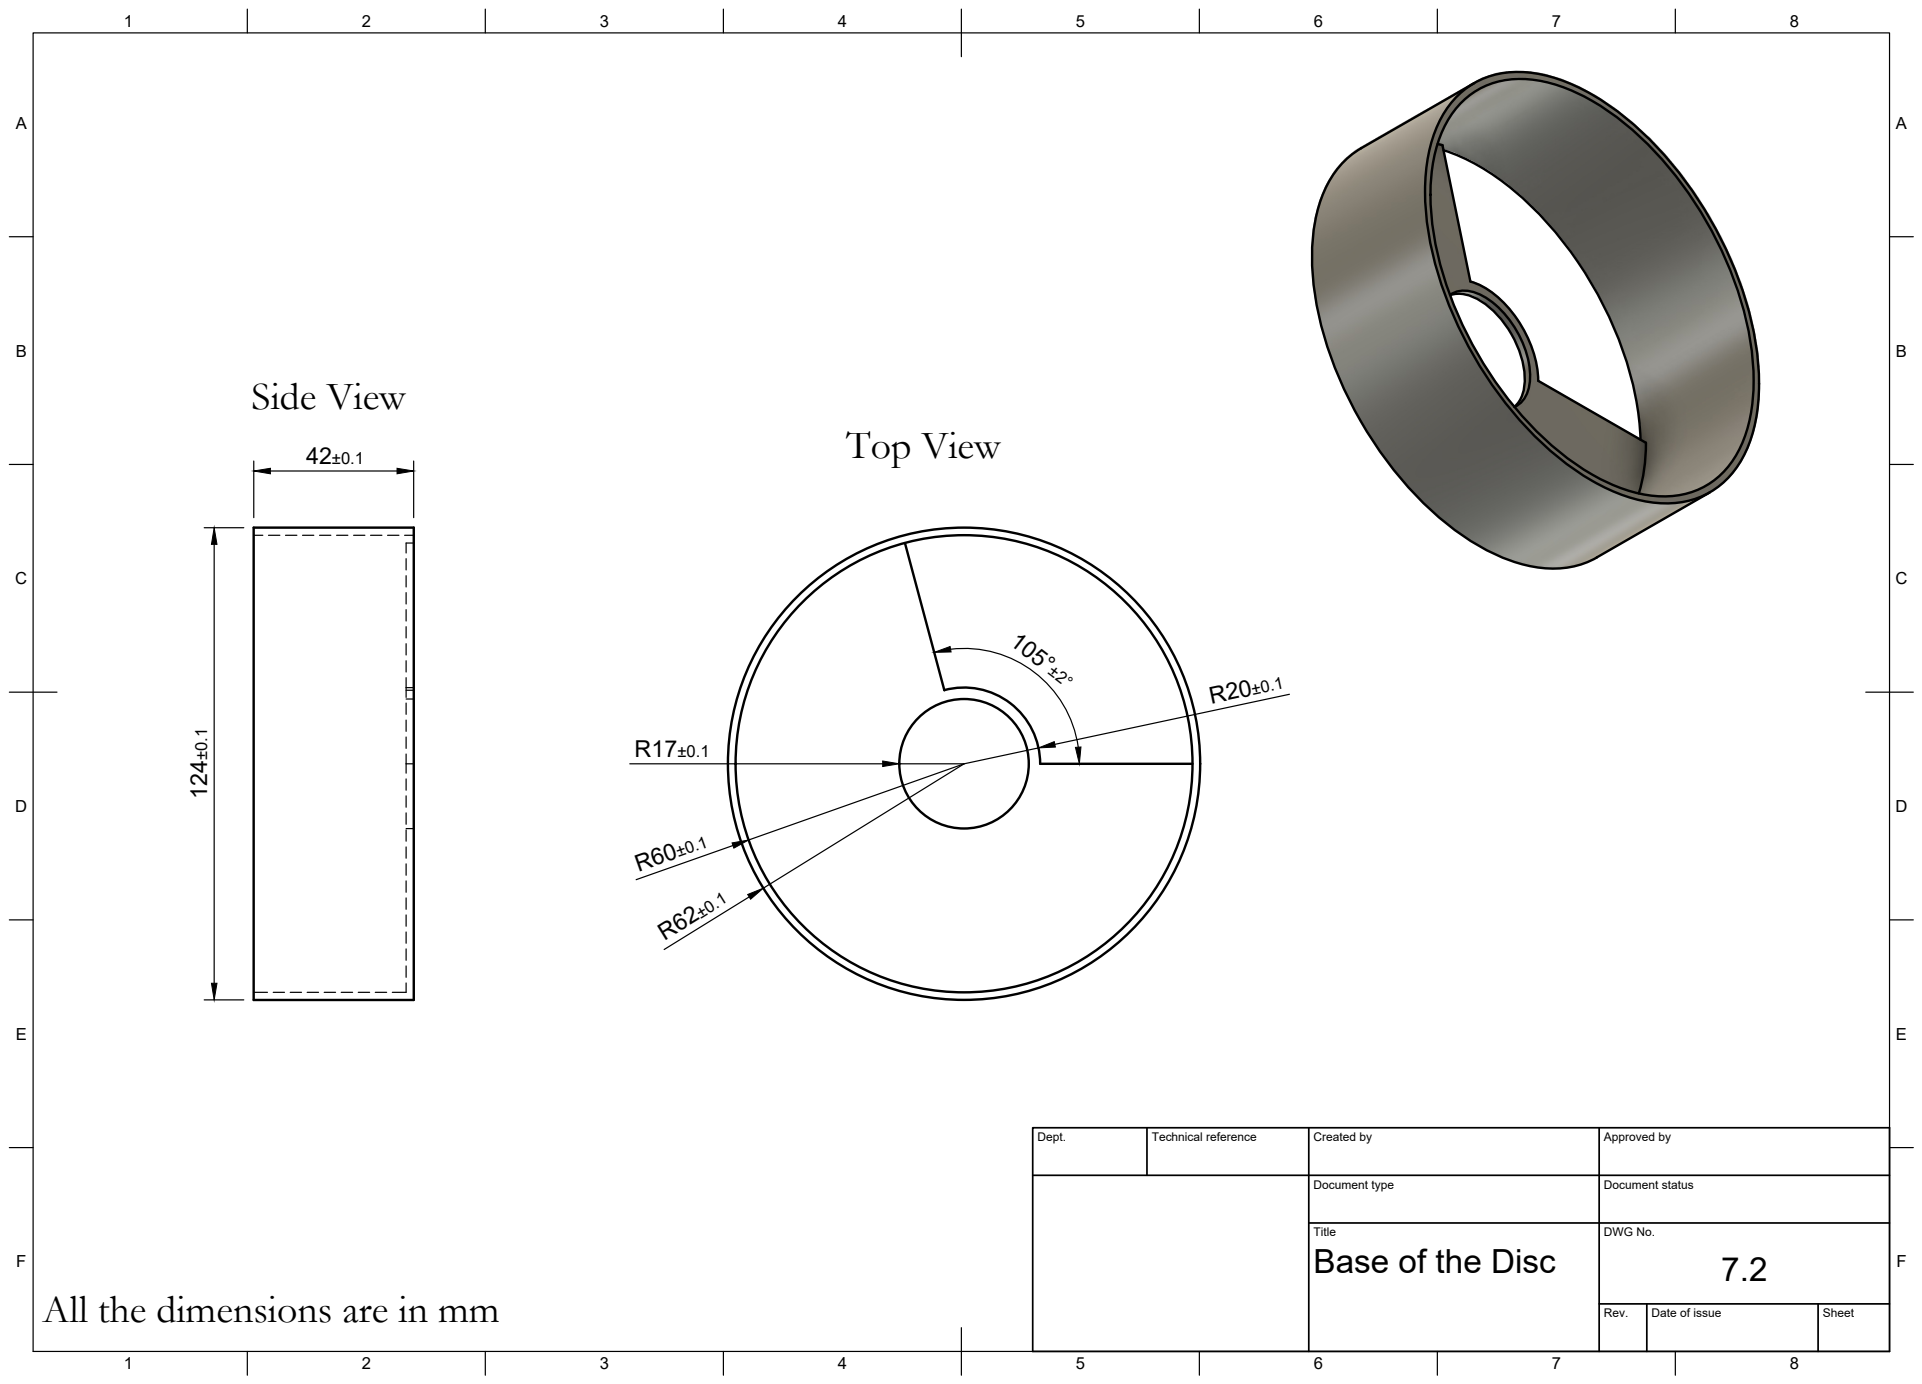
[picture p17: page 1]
Title; DWG No.; Rev.; Date of issue; Sheet; Base of the Disc; Top View; Side View

Dept. | Technical reference | Created by | Approved by

Document type | Document status

All the dimensions are in mm

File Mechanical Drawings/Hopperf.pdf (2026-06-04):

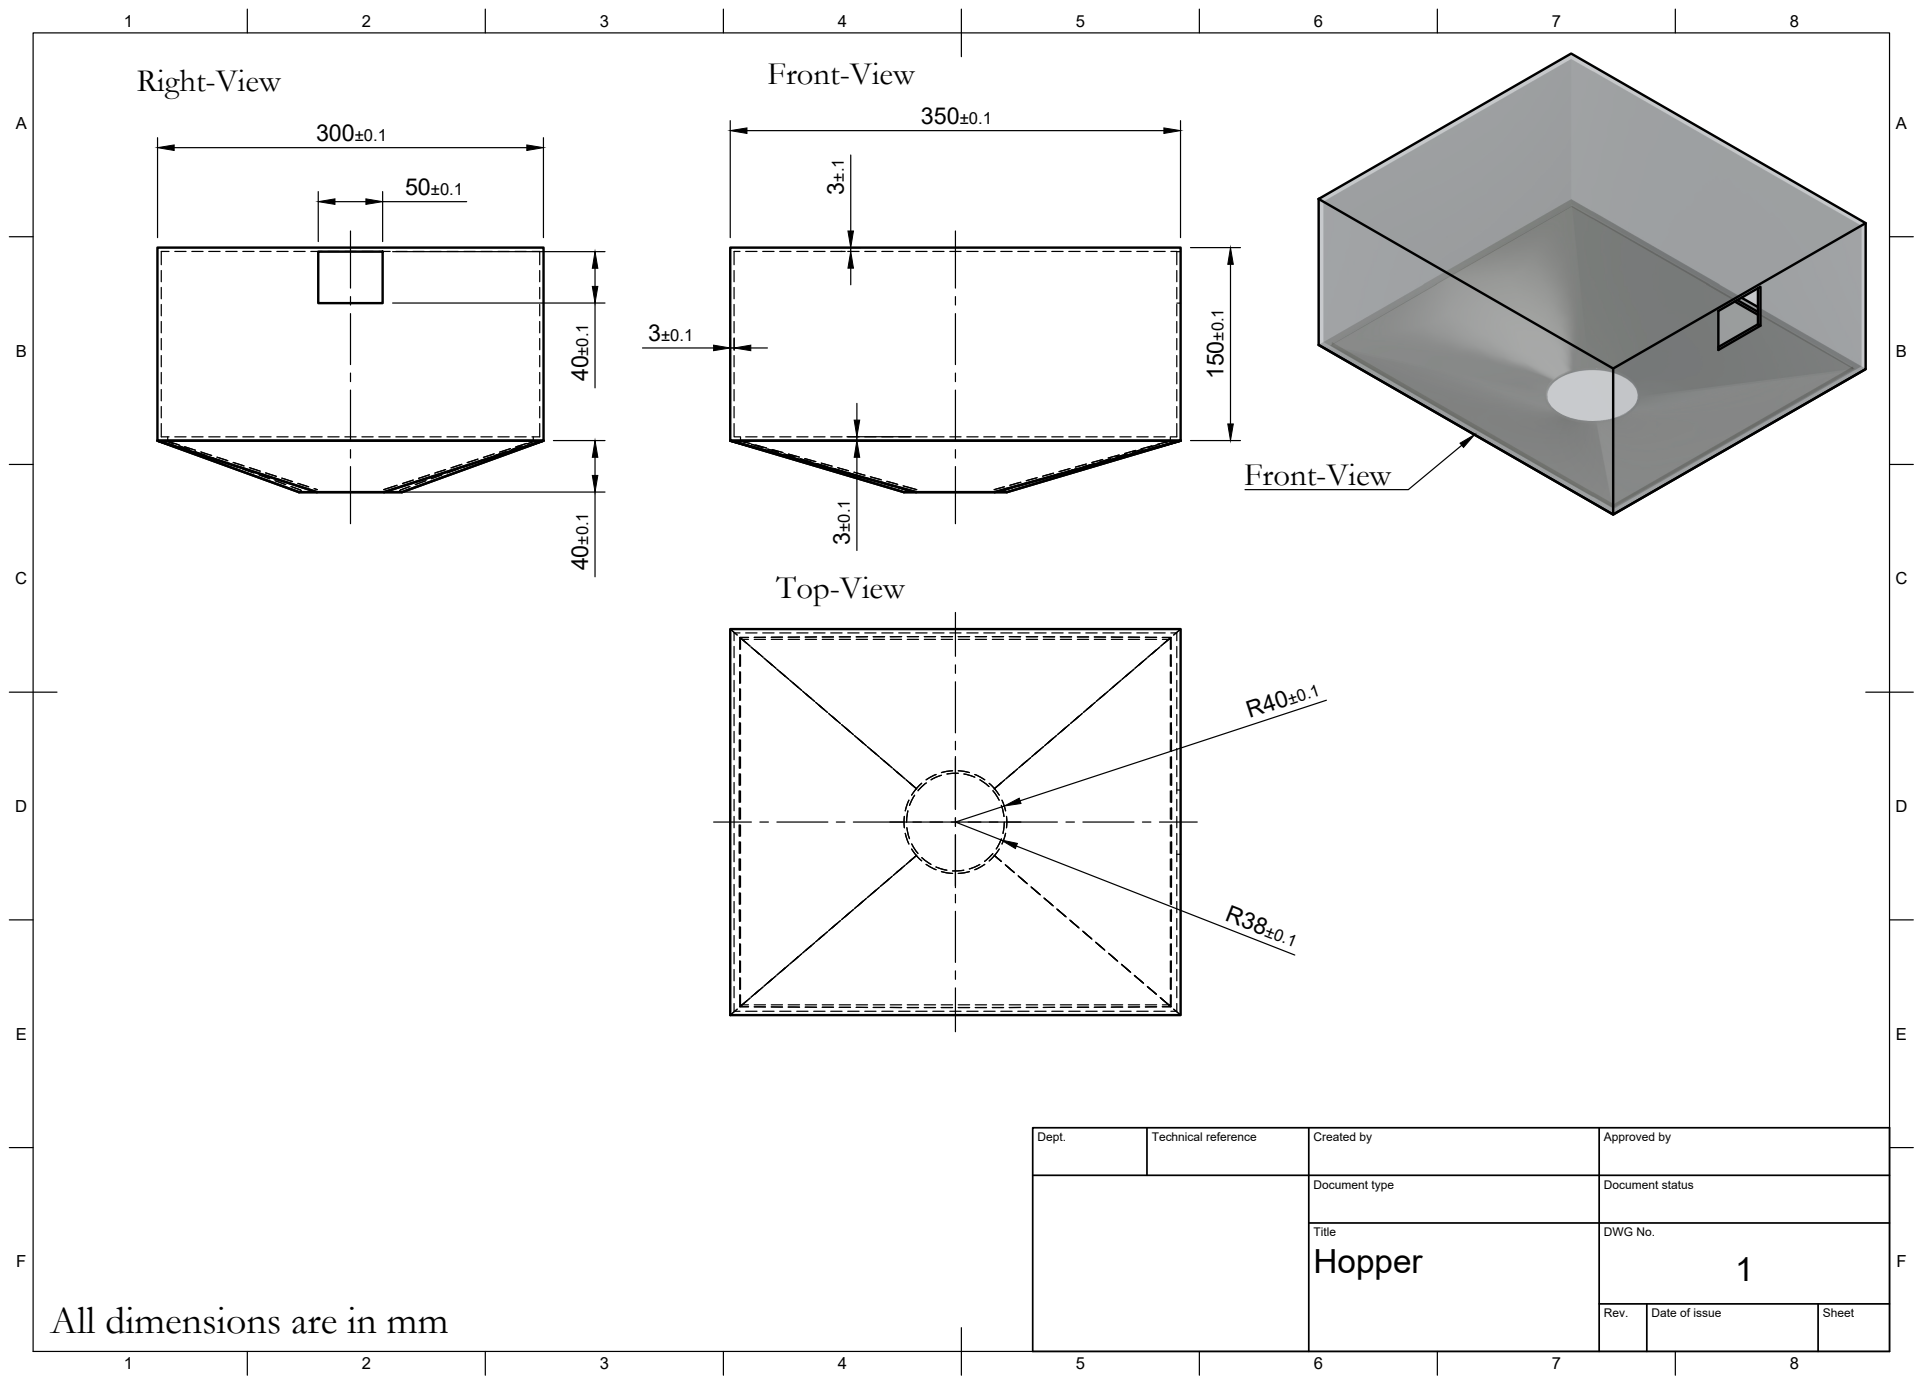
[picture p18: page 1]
Title; DWG No.; Rev.; Date of issue; Sheet

Dept. | Technical reference | Created by | Approved by

Document type | Document status

All dimensions are in mm

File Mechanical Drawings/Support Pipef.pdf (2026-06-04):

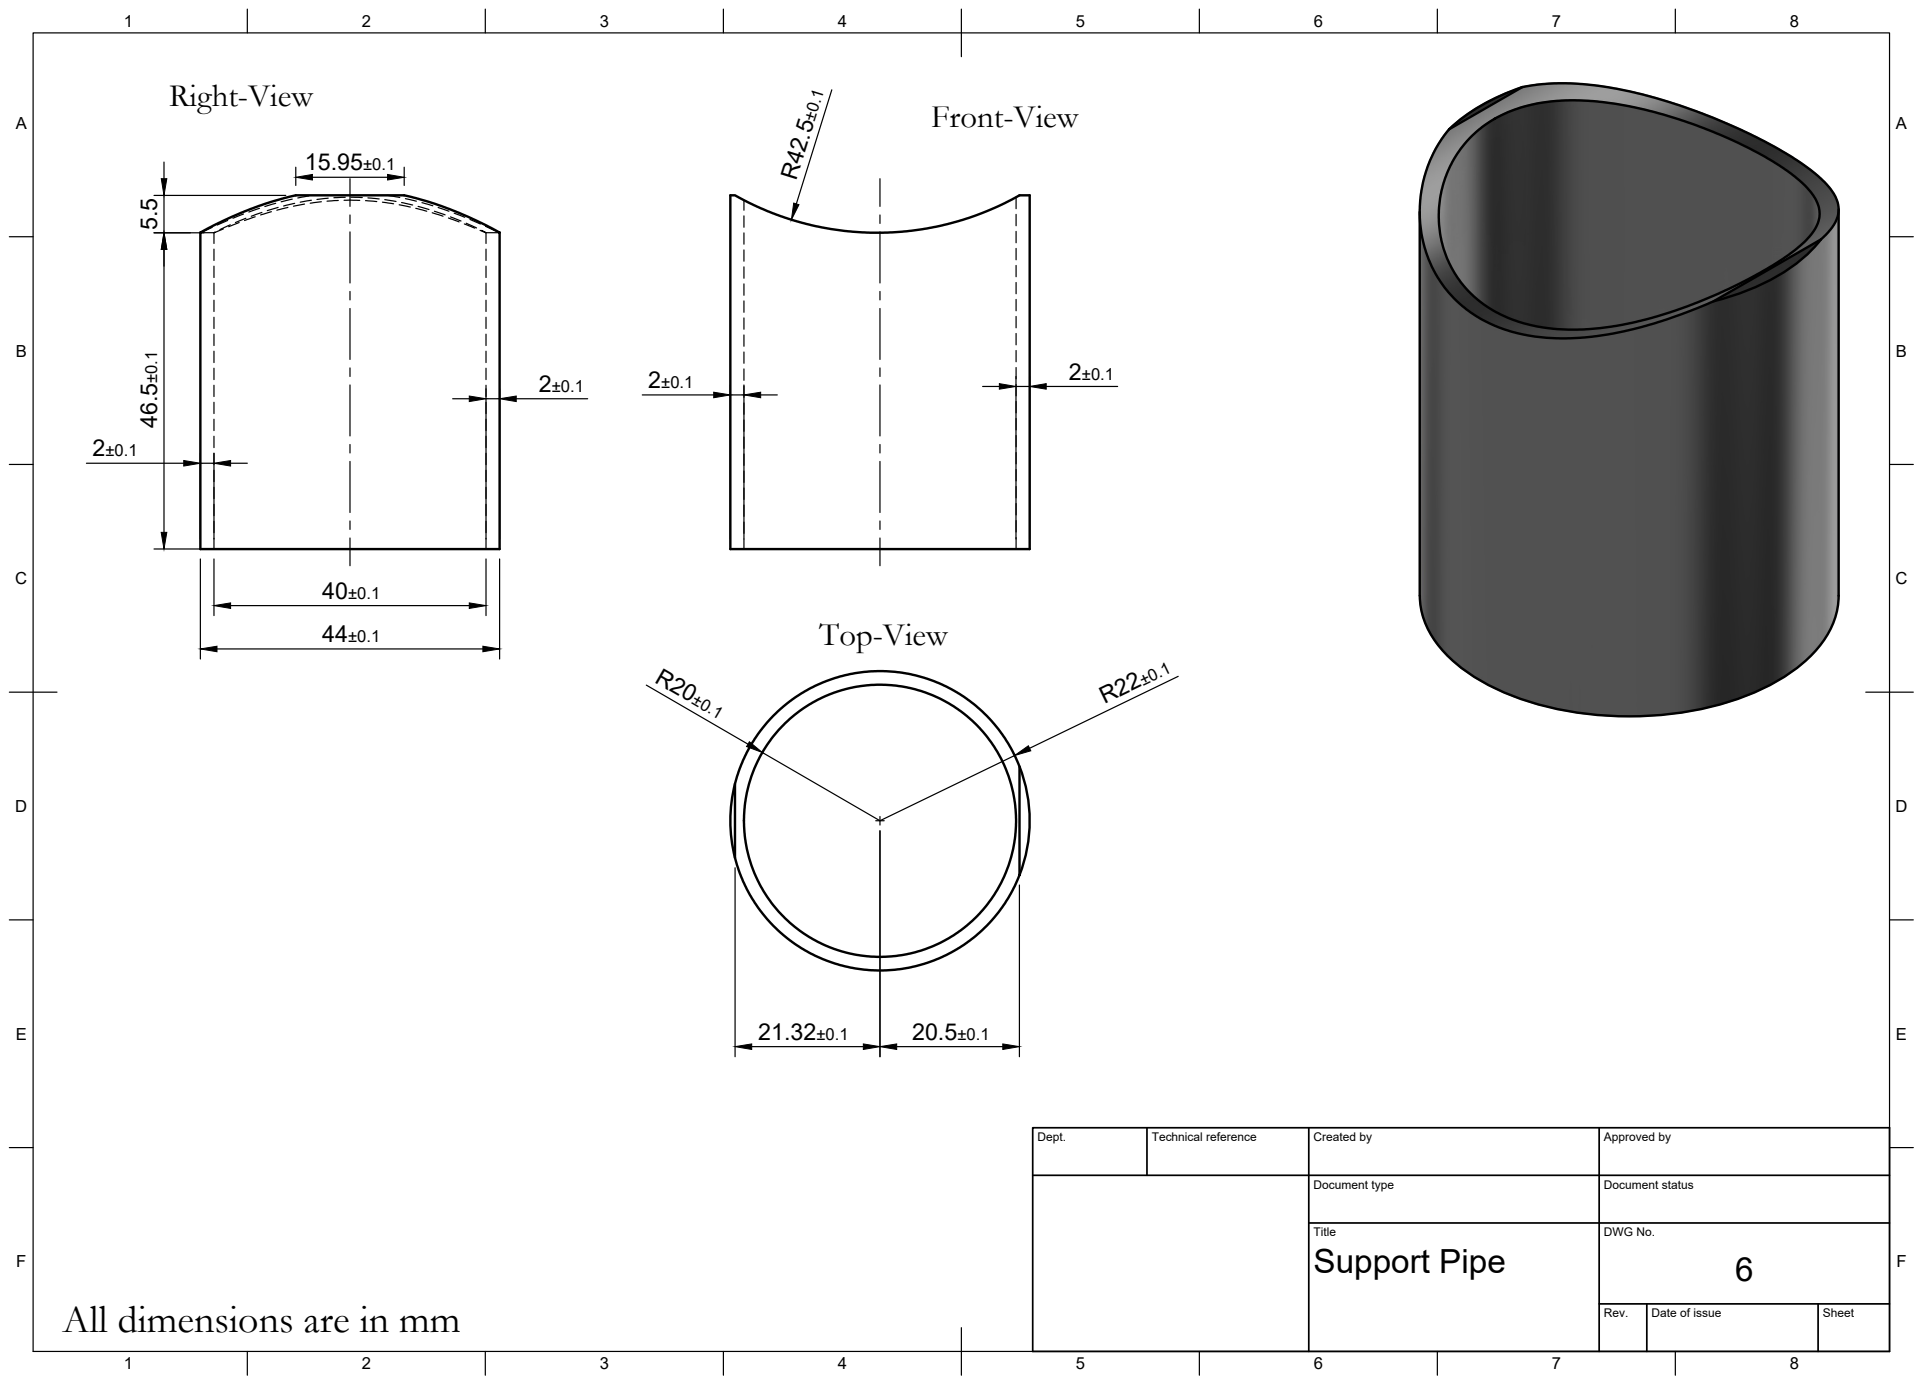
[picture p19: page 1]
Title; DWG No.; Rev.; Date of issue; Sheet; Support Pipe

Front-View Right-View

Dept. | Technical reference | Created by | Approved by

Document type | Document status

All dimensions are in mm

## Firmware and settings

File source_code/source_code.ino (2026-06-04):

#include <BluetoothSerial.h>

BluetoothSerial SerialBT;

/* ------------------- PIN DEFINITIONS ------------------- */

// Agitator DC Motor (L298N)
#define AGITATOR_ENB   33
#define AGITATOR_IN4   32
#define AGITATOR_IN3   4

// Screw Stepper (L298N)
#define SCREW_ENA  25
#define SCREW_IN1  26
#define SCREW_IN2  27
#define SCREW_IN3  14
#define SCREW_IN4  12
#define SCREW_ENB  13

// Disc Stepper (L298N)
#define DISC_ENA  23
#define DISC_IN1  22
#define DISC_IN2  21
#define DISC_IN3  19
#define DISC_IN4  18
#define DISC_ENB  5

/* ------------------- SYSTEM VARIABLES ------------------- */

bool systemRunning = false;
int seedDroppingSpeed = 0;

/* ------------------- PWM CONFIG ------------------- */

#define PWM_FREQ 5000
#define PWM_RESOLUTION 8

/* ------------------- STEPPER VARIABLES ------------------- */

unsigned long lastStepTimeScrew = 0;
unsigned long lastStepTimeDisc = 0;

unsigned long screwInterval = 2000;
unsigned long discInterval = 2000;

int screwStepIndex = 0;
int discStepIndex = 0;

unsigned long lastReverseWindow = 0;
bool reverseActive = false;

const unsigned long REVERSE_INTERVAL = 15000;   // 5 seconds
const unsigned long REVERSE_DURATION = 500;    // 200 ms

unsigned long lastReverseWindowDisc = 0;
bool reverseActiveDisc = false;

/* ------------------- SPEED MAPPING ------------------- */

unsigned long computeScrewInterval(int seedSpeed) {
  return map(seedSpeed, 1, 5, 2000, 10000);
}

unsigned long computeDiscInterval(int seedSpeed) {
  return map(seedSpeed, 1, 5, 2000, 10000);
}

/* ------------------- AGITATOR CONTROL ------------------- */

void controlAgitator() {

  if (systemRunning) {
    digitalWrite(AGITATOR_IN3, HIGH);
    digitalWrite(AGITATOR_IN4, LOW);
    ledcWrite(AGITATOR_ENB, 200);
  } else {
    ledcWrite(AGITATOR_ENB, 0);
  }
}

/* ------------------- STEPPER SEQUENCE ------------------- */

void stepMotor(int in1, int in2, int in3, int in4, int stepIndex) {

  switch (stepIndex % 4) {

    case 0:
      digitalWrite(in1, HIGH); digitalWrite(in2, LOW);
      digitalWrite(in3, HIGH); digitalWrite(in4, LOW);
      break;

    case 1:
      digitalWrite(in1, LOW); digitalWrite(in2, HIGH);
      digitalWrite(in3, HIGH); digitalWrite(in4, LOW);
      break;

    case 2:
      digitalWrite(in1, LOW); digitalWrite(in2, HIGH);
      digitalWrite(in3, LOW); digitalWrite(in4, HIGH);
      break;

    case 3:
      digitalWrite(in1, HIGH); digitalWrite(in2, LOW);
      digitalWrite(in3, LOW); digitalWrite(in4, HIGH);
      break;
  }
}

void stopStepper(int ena, int enb, int in1, int in2, int in3, int in4) {

  digitalWrite(ena, LOW);
  digitalWrite(enb, LOW);

  digitalWrite(in1, LOW);
  digitalWrite(in2, LOW);
  digitalWrite(in3, LOW);
  digitalWrite(in4, LOW);
}

/* ------------------- SCREW CONTROL ------------------- */

void controlScrew() {

  if (!systemRunning) {
    stopStepper(SCREW_ENA, SCREW_ENB,
                SCREW_IN1, SCREW_IN2, SCREW_IN3, SCREW_IN4);
    return;
  }

  digitalWrite(SCREW_ENA, HIGH);
  digitalWrite(SCREW_ENB, HIGH);

  unsigned long currentMillis = millis();

  // Trigger reverse every 5 seconds
  if (currentMillis - lastReverseWindow >= REVERSE_INTERVAL) {
    lastReverseWindow = currentMillis;
    reverseActive = true;
  }

  // Stop reverse after 200 ms
  if (reverseActive && (currentMillis - lastReverseWindow >= REVERSE_DURATION)) {
    reverseActive = false;
  }

  screwInterval = computeScrewInterval(seedDroppingSpeed);

  if (micros() - lastStepTimeScrew >= screwInterval) {
    lastStepTimeScrew = micros();

    if (reverseActive) {
      screwStepIndex--;  // reverse direction
    } else {
      screwStepIndex++;  // forward direction
    }

    stepMotor(SCREW_IN1, SCREW_IN2, SCREW_IN3, SCREW_IN4, screwStepIndex);
  }
}

/* ------------------- DISC CONTROL ------------------- */

void controlDisc() {

  if (!systemRunning) {
    stopStepper(DISC_ENA, DISC_ENB,
                DISC_IN1, DISC_IN2, DISC_IN3, DISC_IN4);
    return;
  }

  digitalWrite(DISC_ENA, HIGH);
  digitalWrite(DISC_ENB, HIGH);

  unsigned long currentMillis = millis();

  // Trigger reverse every 5 seconds
  if (currentMillis - lastReverseWindowDisc >= REVERSE_INTERVAL) {
    lastReverseWindowDisc = currentMillis;
    reverseActiveDisc = true;
  }

  // Stop reverse after 200 ms
  if (reverseActiveDisc &&
      (currentMillis - lastReverseWindowDisc >= REVERSE_DURATION)) {
    reverseActiveDisc = false;
  }

  discInterval = computeDiscInterval(seedDroppingSpeed);

  if (micros() - lastStepTimeDisc >= discInterval) {

    lastStepTimeDisc = micros();

    if (reverseActiveDisc) {
      discStepIndex--;   // reverse
    } else {
      discStepIndex++;   // forward
    }

    stepMotor(DISC_IN1, DISC_IN2, DISC_IN3, DISC_IN4, discStepIndex);
  }
}

/* ------------------- BLUETOOTH HANDLING ------------------- */

void readBluetooth() {

  if (SerialBT.available()) {

    String command = SerialBT.readStringUntil('\n');
    command.trim();

    Serial.print("Received Command: ");
    Serial.println(command);

    if (command == "START") {
      systemRunning = true;
      Serial.println("System STARTED");
    }

    else if (command == "STOP") {
      systemRunning = false;
      Serial.println("System STOPPED");
    }

    else if (command.startsWith("SPEED:")) {
      seedDroppingSpeed = command.substring(6).toInt();
      seedDroppingSpeed = constrain(seedDroppingSpeed, 0, 100);

      Serial.print("Speed Set To: ");
      Serial.println(seedDroppingSpeed);
    }
  }
}

/* ------------------- SETUP ------------------- */

void setup() {

  Serial.begin(9600);
  SerialBT.begin("AKS");   // Bluetooth device name

  Serial.println("ESP32 TMP Controller Started");
  Serial.println("Bluetooth Device Name: AKS");

  pinMode(AGITATOR_IN3, OUTPUT);
  pinMode(AGITATOR_IN4, OUTPUT);
  pinMode(AGITATOR_ENB, OUTPUT);

  pinMode(SCREW_ENA, OUTPUT);
  pinMode(SCREW_ENB, OUTPUT);
  pinMode(SCREW_IN1, OUTPUT);
  pinMode(SCREW_IN2, OUTPUT);
  pinMode(SCREW_IN3, OUTPUT);
  pinMode(SCREW_IN4, OUTPUT);

  pinMode(DISC_ENA, OUTPUT);
  pinMode(DISC_ENB, OUTPUT);
  pinMode(DISC_IN1, OUTPUT);
  pinMode(DISC_IN2, OUTPUT);
  pinMode(DISC_IN3, OUTPUT);
  pinMode(DISC_IN4, OUTPUT);

  ledcAttach(AGITATOR_ENB, PWM_FREQ, PWM_RESOLUTION);
}

/* ------------------- MAIN LOOP ------------------- */

void loop() {

  readBluetooth();
  controlAgitator();
  controlScrew();
  controlDisc();
}




// repurpose code with TMC2209 instead of L289 for stepper
